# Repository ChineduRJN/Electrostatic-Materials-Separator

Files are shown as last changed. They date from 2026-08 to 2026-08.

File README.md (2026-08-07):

# Electrostatic Materials Separator — Embedded Control & High-Voltage System

A multidisciplinary industrial automation machine engineered to separate metallic and non-metallic particles using high-voltage electrostatic fields. This system integrates a master-slave dual-microcontroller architecture, custom mixed-signal conditioning circuits, high-power AC/DC switching, and a real-time graphical touchscreen interface.

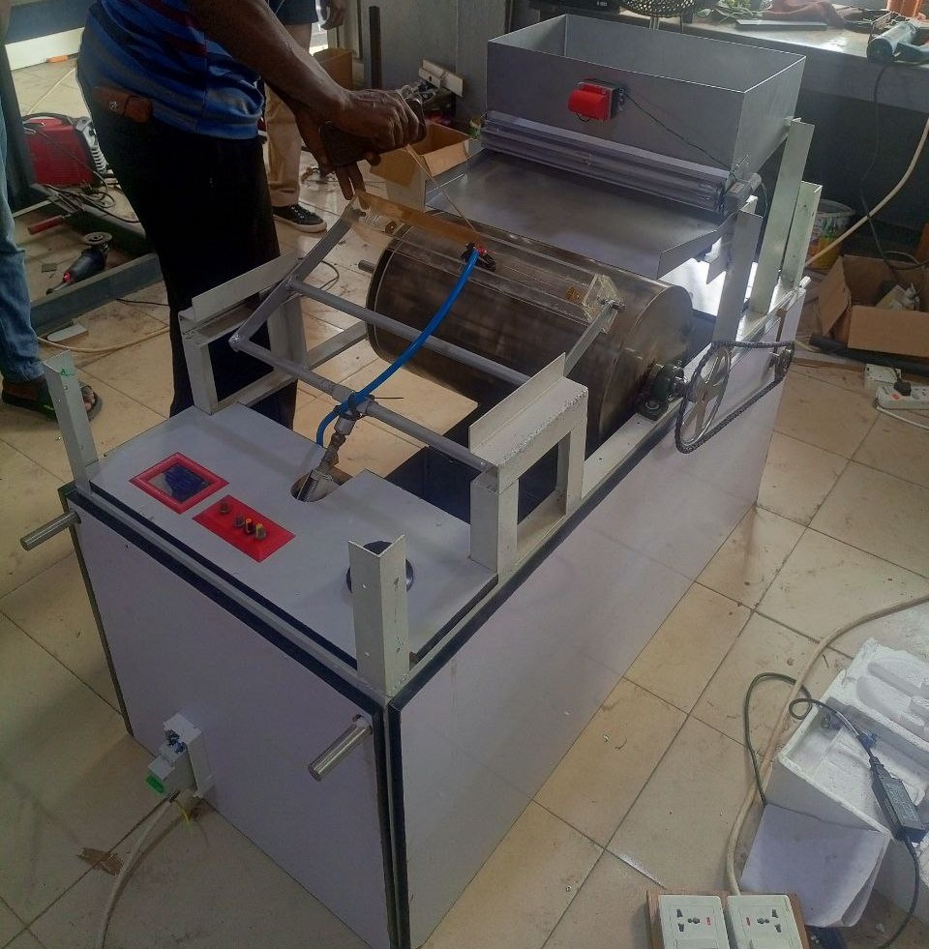
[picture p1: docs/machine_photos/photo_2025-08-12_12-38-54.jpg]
Electrostatic Separator Complete Assembly


---

## 📊 System Overview & Key Features

| Subsystem | Specification / Implementation | Technical Role |
| :--- | :--- | :--- |
| **Main System Controller** | **Arduino Mega 2560 Pro** | Central brain; executes UI rendering, Variac voltage sampling, and actuator PWM logic |
| **Dedicated Sensor Node** | **Arduino Pro Mini** | Dedicated edge processor; samples Hall sensor pulses and computes drum RPM |
| **Inter-MCU Communication** | **SPI / UART Handshake** | Real-time sensor telemetry transfer from slave (Pro Mini) to master (Mega) |
| **High-Voltage Generation** | **Variac & Step-Up Transformer** | Generates adjustable electrostatic field for metallic particle deflection |
| **HV Signal Conditioning** | **Op-Amps, TIP31C, Passive Filters** | Steps down and buffers transformer feedback for accurate microcontroller ADC monitoring |
| **Interactive UI** | **3.5" ILI9488 TFT Touchscreen** | Graphical display rendering live RPM, electrostatic voltage (kV), feeder rate, and vibration % |
| **Actuation & Feeding** | **ESC, DC Motor, 2x Tray Vibrators** | Regulates drum rotation speed and consistent feeder tray/hopper material flow (0–100%) |

---

## 🛠️ Key Engineering Highlights

### 1. Master-Slave Dual-Microcontroller Architecture
* **Task Offloading:** To prevent display rendering loops on the **Arduino Mega 2560 Pro** from missing high-speed sensor interrupts, an **Arduino Pro Mini** was deployed as a dedicated sensor coprocessor  .
* **RPM Acquisition:** The Pro Mini continuously captures pulses from a magnetic **Hall effect sensor** mounted on the rotating separation drum, calculates instantaneous revolutions per minute (RPM), and transmits structured telemetry packets to the main controller over **SPI**  .

### 2. High-Voltage Signal Conditioning & Mixed-Signal PCB
* **Transformer Feedback Monitoring:** Designed and soldered an analog signal conditioning circuit using **operational amplifiers, capacitors, diodes, resistors, and TIP31C power transistors**  .
* **Safe ADC Sampling:** This circuit conditions and scales the high-voltage output from the Variac/transformer stage into a safe, linear 0–5V analog range, allowing the Mega to monitor and display live electrostatic voltage (in kV) on the touchscreen.
* **Power & Noise Isolation:** Implemented an **XL4015 DC-DC buck converter** to supply a clean 5V rail to the logic boards, isolating the low-voltage microcontrollers from electromagnetic noise generated by the industrial AC contactors and feeder vibrators  .

### 3. Real-Time Graphical UI & Electromechanical Control
* **TFT Interface:** Programmed a graphical dashboard on an **ILI9488 TFT screen** to give operators real-time feedback on drum speed, feeder speed, electrostatic voltage, and vibration intensity  .
* **Precision Material Flow:** Configured PWM control logic to independently drive an **Electronic Speed Controller (ESC)** for drum rotation and dual industrial vibrators on the feeder tray and hopper (adjustable from 0% to 100% intensity)  .

---

## 📂 Repository Structure

```text
Electrostatic-Materials-Separator/
├── firmware/
│   ├── mega_main_controller/    # Arduino Mega 2560 Pro code (TFT UI, Actuators & Main Loop)
│   └── pro_mini_rpm_sensor/     # Arduino Pro Mini code (Hall Sensor Interrupts & SPI Transmit)
├── hardware/
│   ├── schematics/              # Signal conditioning schematic diagrams & PCB layouts
│   └── bom.md                   # Complete Bill of Materials (Electronics, HV & Mechanical)
└── docs/
    ├── machine_photos/          # Finished machine, wooden/glass casing, and TFT display
    └── assembly_and_wiring/     # Internal control wiring, terminal blocks, and mechanical frame

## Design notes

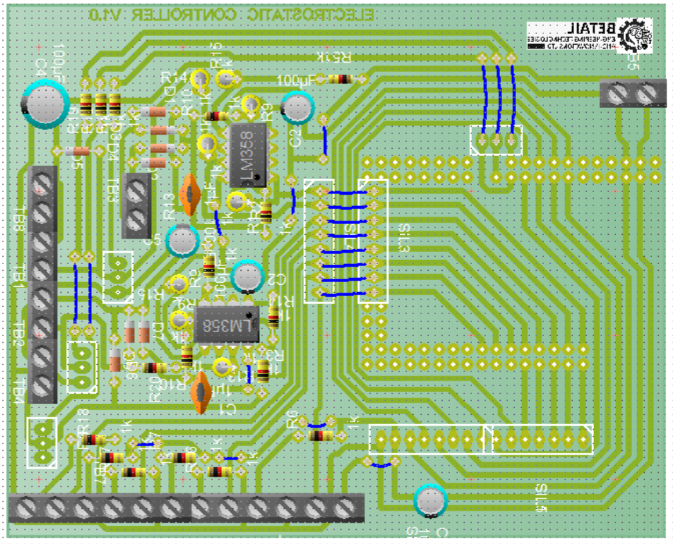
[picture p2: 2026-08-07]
hardware/schematics/pcb1.png

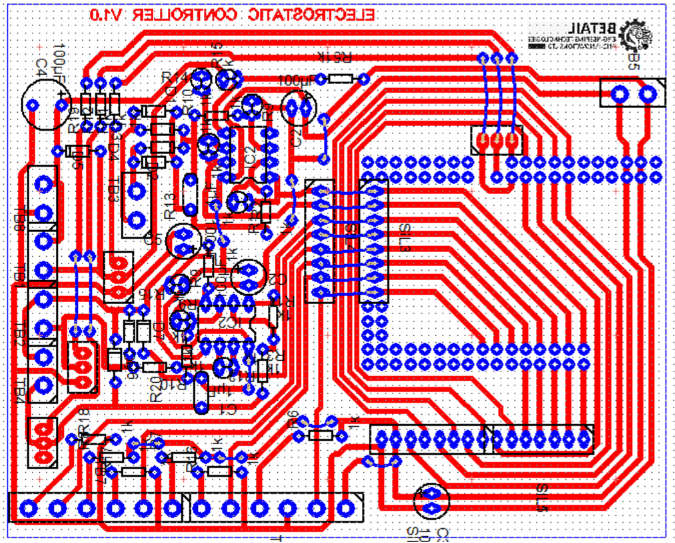
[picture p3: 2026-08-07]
hardware/schematics/pcb2.png

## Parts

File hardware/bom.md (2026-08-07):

# Bill of Materials (BoM) — Electrostatic Materials Separator

| Subsystem | Component | Purpose / Description |
| :--- | :--- | :--- |
| **Microcontrollers** | Arduino Mega 2560 Pro | Central controller; manages TFT display, Variac voltage sampling, and actuator logic |
| **Microcontrollers** | Arduino Pro Mini | Dedicated sensor node; processes Hall sensor pulses for RPM and sends over SPI/UART |
| **User Interface** | ILI9488 TFT Screen | Graphical display showing live RPM, voltage (kV), feeder speed, and vibration % |
| **High Voltage** | Variac & Transformer | Generates adjustable electrostatic field for metallic/non-metallic separation |
| **Power Supply** | XL4015 DC-DC Buck | Steps down input supply to provide a stable 5V rail for microcontrollers |
| **Power Switching** | Industrial Contactors | High-power AC switching for main system power and motor isolation |
| **Signal Conditioning** | TIP31C & Op-Amps | Amplifies and conditions high-voltage transformer feedback for ADC monitoring |
| **Electromechanical** | Hall Effect Sensor | Measures drum revolutions per minute via mounted neodymium magnets |
| **Electromechanical** | ESC & Drum Motor | Regulates rotating drum speed using microcontroller PWM control |
| **Electromechanical** | 2x Tray Vibrators | Controls steady material flow across the feeder tray and hopper (0–100% intensity) |

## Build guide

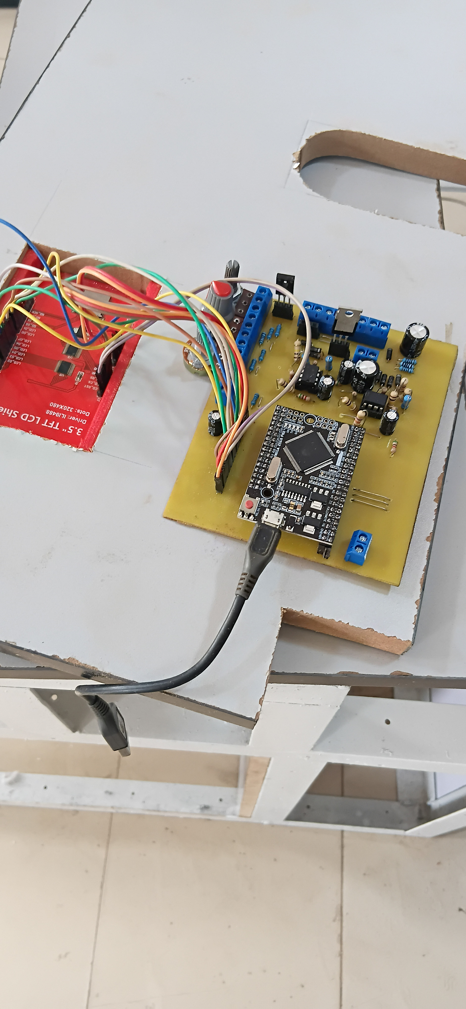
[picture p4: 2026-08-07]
docs/assembly_and_wiring/20250806_120954.jpg

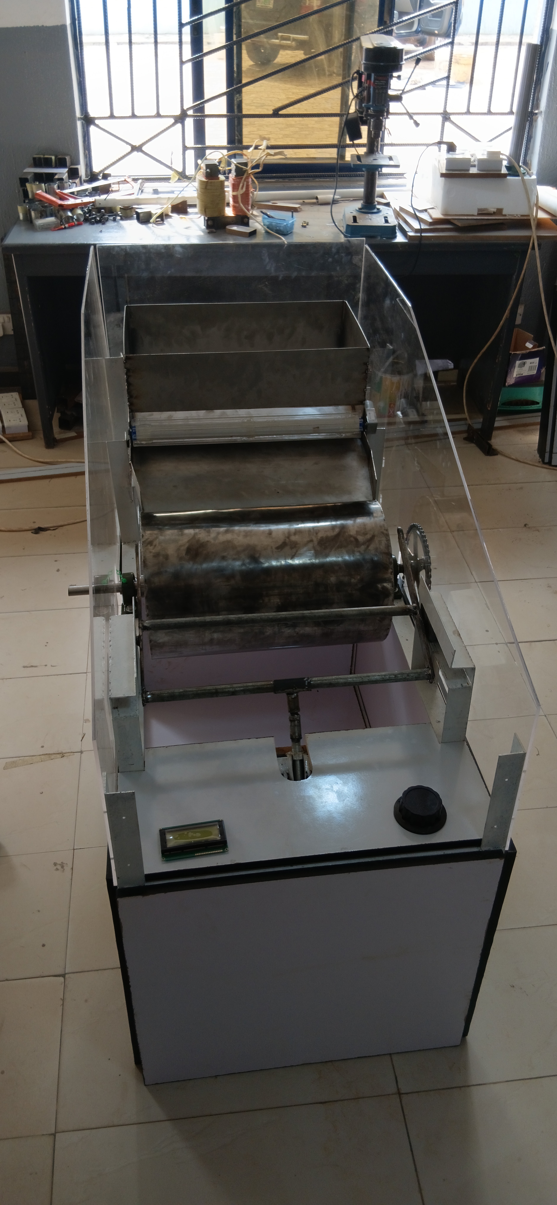
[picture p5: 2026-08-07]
docs/assembly_and_wiring/20250730_100324.jpg

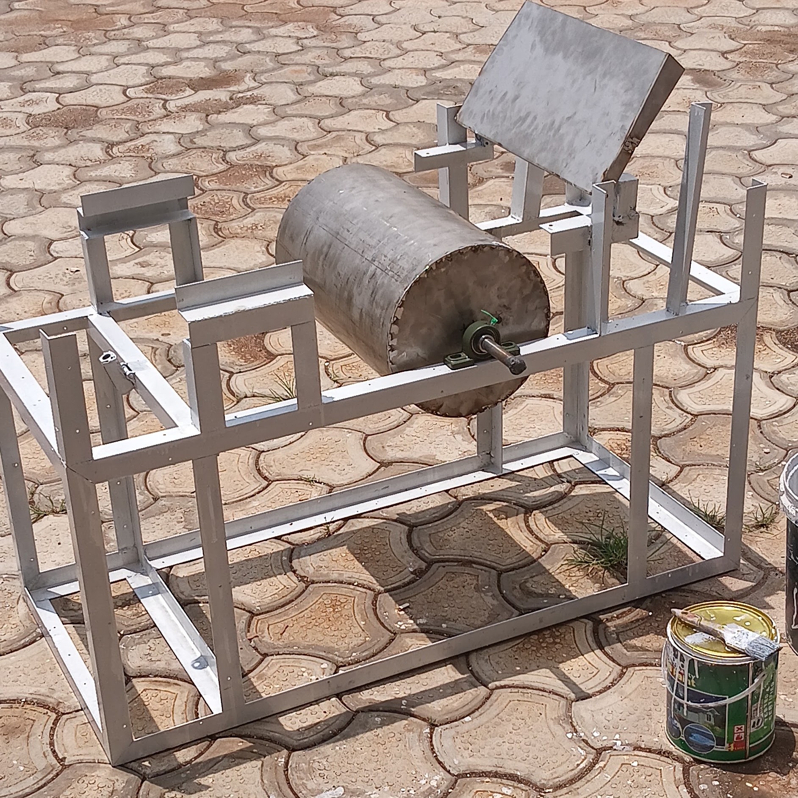
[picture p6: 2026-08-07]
docs/assembly_and_wiring/20250729_120056.jpg

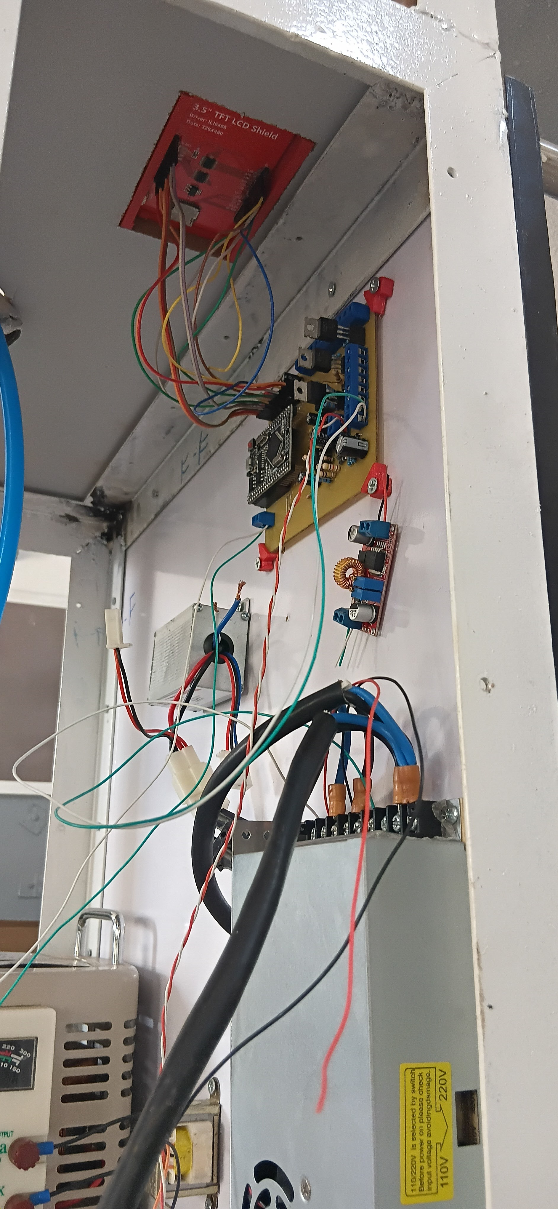
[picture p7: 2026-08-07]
docs/assembly_and_wiring/20250809_114631 (2).jpg

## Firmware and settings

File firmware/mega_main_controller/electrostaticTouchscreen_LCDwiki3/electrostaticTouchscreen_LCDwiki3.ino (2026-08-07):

#include <LCDWIKI_GUI.h> // Core graphics library
#include <LCDWIKI_KBV.h> // Hardware-specific library
#include <TouchScreen.h> // Touchscreen support

// Initialize TFT screen
LCDWIKI_KBV tft(320, 480, A6, A4, A2, A0, A8);//width,height,cs,cd,wr,rd,reset

// Colors
#define BLACK        0x0000
#define BLUE         0x001F
#define RED          0xF800
#define GREEN        0x07E0
#define CYAN         0x07FF
#define MAGENTA      0xF81F
#define YELLOW       0xFFE0
#define WHITE        0xFFFF
#define NAVY         0x000F
#define DARKGREEN    0x03E0
#define DARKCYAN     0x03EF
#define MAROON       0x7800
#define PURPLE       0x780F 
#define OLIVE        0x7BE0 
#define GREY         0xC618 
#define DARKGREY     0x7BEF
#define ORANGE       0xFD20
#define GREENYELLOW  0xAFE5
#define PINK         0xF81F

// Touchscreen pins
#define YP A2
#define XM A3
#define YM 8
#define XP 9
TouchScreen ts = TouchScreen(XP, YP, XM, YM, 300);

// Calibrated values from touch test
#define TS_LEFT  93
#define TS_RT    926
#define TS_TOP   879
#define TS_BOT   154

// Pin definitions
#define energies_pin 17
#define feed_pin 10
#define hopper_pin 12
#define tray_pin 11
#define drumCont 46

// Serial communication for RPM data
#define rpmSerial Serial1

TSPoint p;
    
//Controls
int feed_nobe = A13;
int hopper_nobe = A11;
int tray_nobe = A9;

int feed_nobe_val;
int hopper_nobe_val;
int tray_nobe_val;

int * feed_val = &feed_nobe_val;
int * hopper_val = &hopper_nobe_val;
int * tray_val = &tray_nobe_val;

//Sensors
int staticVolt_meter = A1;
int feed_meter = A3;
int hopper_meter = A5;
int tray_meter = A7;
int drum_meter;

bool isRunning = false;
unsigned long lastUpdateTime = 0;
unsigned long * lastUpdateTime_P = &lastUpdateTime;
unsigned long TouchInt = 0;
unsigned long * TouchInt_P = &TouchInt;
const unsigned long updateInterval = 2000;
const unsigned long * updateInterval_P = &updateInterval;

unsigned long distime = 0;
unsigned long * dis_t = &distime;

// RPM variables 
int rawDrumSpeed = 0;        // Raw RPM value from Arduino Pro Mini
int drumSpeed = 0;           // Calibrated RPM value for display
unsigned long lastRpmReceived = 0;  // Timestamp of last RPM data received

int * drumSpeed_P = &drumSpeed;
double electrostatic = 0.00;
double * electrostatic_P = &electrostatic;
int feedSpeed = 1;
int * feedSpeed_P = &feedSpeed;
int hopperVib = 1;
int * hopperVib_P = &hopperVib;
int trayVib = 1;
int * trayVib_P = &trayVib;

// Cache previous values to reduce flickering
int lastDrumSpeed;
int * lastDrumSpeed_P = &lastDrumSpeed;
float lastElectrostatic;
float * lastElectrostatic_P = &lastElectrostatic;
float lastFeedSpeed;
float * lastFeedSpeed_P = &lastFeedSpeed;
float lastHopperVib;
float * lastHopperVib_P = &lastHopperVib;
float lastTrayVib;
float * lastTrayVib_P = &lastTrayVib;

// Positions
int yStart = 100;
int * yStart_P = &yStart;
int spacing = 40;
int * spacing_P = &spacing;
int valueX = 200;
int * valueX_P = &valueX;
int unitX = 290;
int * unitX_P = &unitX;

//  RPM Data Reading Function
void readRPMData() {
  // Check for incoming RPM data from Arduino Pro Mini
  if (rpmSerial.available()) {
    String rpmString = rpmSerial.readStringUntil('\n');
    rawDrumSpeed = rpmString.toInt();
    
    // Apply calibration factor only once when receiving new data
    drumSpeed = rawDrumSpeed * 0.3289;  // Your calibration factor
    
    lastRpmReceived = millis();
  }
  
  // Timeout handling - set RPM to 0 if no data received for 1 second
  if (millis() - lastRpmReceived > 1000) {
    drumSpeed = 0;
    rawDrumSpeed = 0;
  }
}

void showIntroScreen() {
  tft.Fill_Screen(BLACK);
  tft.Set_Text_Back_colour(BLACK);
  tft.Set_Text_colour(CYAN);
  tft.Set_Text_Size(6);
  tft.Print_String("BETAIL.NG", CENTER, 130);

  delay(3000); // show for 3 seconds
}

void drawStaticLabels() {
  tft.Set_Text_colour(WHITE);
  tft.Set_Text_Back_colour(BLACK);
  tft.Set_Text_Size(2);

  // Labels
  tft.Print_String("Drum speed:", 10, *yStart_P);
  tft.Print_String("Electrostatic:", 10, *yStart_P + *spacing_P);
  tft.Print_String("Feeding speed:", 10, *yStart_P + 2 * *spacing_P);
  tft.Print_String("Hopper vibrator:", 10, *yStart_P + 3 * *spacing_P);
  tft.Print_String("Tray vibrator:", 10, *yStart_P + 4 * *spacing_P);

  // Units (static)
  tft.Print_String("RPM", *unitX_P, *yStart_P);
  tft.Print_String("kV", *unitX_P, *yStart_P + *spacing_P);
  tft.Print_String("RPM", *unitX_P, *yStart_P + 2 * *spacing_P);
  tft.Print_String("%", *unitX_P, *yStart_P + 3 * *spacing_P);
  tft.Print_String("%", *unitX_P, *yStart_P + 4 * *spacing_P);
}

void updateValues() {
  tft.Set_Text_Mode(1);
  tft.Set_Text_colour(WHITE);
  tft.Set_Text_Back_colour(BLACK);
  tft.Set_Text_Size(2);

  char buf[6];
  int boxWidth = 80; // width of the value display box (pixels)
  int charWidth = 6 * tft.Get_Text_Size(); // width of one char
  int x;

  if (*drumSpeed_P != *lastDrumSpeed_P) {
    sprintf(buf, "%3d", *drumSpeed_P); // Display as integer RPM
    int textWidth = strlen(buf) * charWidth;
    x = valueX + boxWidth - textWidth;
    tft.Fill_Rect(*valueX_P, *yStart_P, boxWidth, *spacing_P, BLACK);
    tft.Print_String(buf, x, *yStart_P);
    *lastDrumSpeed_P = *drumSpeed_P;
  }
  
  if (*electrostatic_P != *lastElectrostatic_P) {
    dtostrf(*electrostatic_P, 5, 2, buf);
    int textWidth = strlen(buf) * charWidth;
    x = valueX + boxWidth - textWidth;
    tft.Set_Text_colour(isRunning ? RED : WHITE);
    tft.Fill_Rect(*valueX_P, *yStart_P + *spacing_P, boxWidth, *spacing_P, BLACK);
    tft.Print_String(buf, x, *yStart_P + *spacing_P);
    *lastElectrostatic_P = *electrostatic_P;
    tft.Set_Text_colour(WHITE);
  }
  
  if (*feedSpeed_P != *lastFeedSpeed_P) {
    dtostrf(*feedSpeed_P, 5, 2, buf);
    int textWidth = strlen(buf) * charWidth;
    x = valueX + boxWidth - textWidth;
    tft.Fill_Rect(*valueX_P, *yStart_P + 2 * *spacing_P, boxWidth, *spacing_P, BLACK);
    tft.Print_String(buf, x, *yStart_P + 2 * *spacing_P);
    *lastFeedSpeed_P = *feedSpeed_P;
  }

  if (*hopperVib_P != *lastHopperVib_P) {
    sprintf(buf, "%3d", *hopperVib_P); // fixed-width 3-digit integer
    int textWidth = strlen(buf) * charWidth;
    x = valueX + boxWidth - textWidth;
    tft.Fill_Rect(*valueX_P, *yStart_P + 3 * *spacing_P, boxWidth, *spacing_P, BLACK);
    tft.Print_String(buf, x, *yStart_P + 3 * *spacing_P);
    *lastHopperVib_P = *hopperVib_P;
  }

  if (*trayVib_P != *lastTrayVib_P) {
    sprintf(buf, "%3d", *trayVib_P);
    int textWidth = strlen(buf) * charWidth;
    x = valueX + boxWidth - textWidth;
    tft.Fill_Rect(*valueX_P, *yStart_P + 4 * *spacing_P, boxWidth, *spacing_P, BLACK);
    tft.Print_String(buf, x, *yStart_P + 4 * *spacing_P);
    *lastTrayVib_P = *trayVib_P;
  }
}

void show_string(uint8_t *str,int16_t x,int16_t y,double csize,uint16_t fc, uint16_t bc,boolean mode)
{
    tft.Set_Text_Mode(mode);
    tft.Set_Text_Size(csize);
    tft.Set_Text_colour(fc);
    tft.Set_Text_Back_colour(bc);
    tft.Print_String(str,x,y);
}

void getVal(double * a_val, int aveg, int log_pin){
  double sum = 0.0;
  for (int i=0; i<aveg; i++){
    sum = sum + analogRead(log_pin);
    delay(5);
  }
  *a_val = sum/aveg;
}

void getValint(int * a_val, int aveg, int log_pin){
  int sum = 0.0;
  for (int i=0; i<aveg; i++){
    sum = sum + analogRead(log_pin);
    delay(5);
  }
  *a_val = sum/aveg;
}

void randomizeValues() {
  getVal(&electrostatic, 15, staticVolt_meter);

  //  Removed the problematic line that was continuously modifying drumSpeed
  // *drumSpeed_P = *drumSpeed_P * 0.3289;  // REMOVED THIS LINE
  
  *electrostatic_P = (*electrostatic_P/1023 * 5.00) * 75.00;

// Hopper Vibration Control
  *hopperVib_P = map(*hopperVib_P, 0, 128, 0, 178);
  *hopper_val = map(*hopper_val, 100, 975, 0, 178);
  
  int pinWriter = *hopperVib_P;
  if (*hopper_val > pinWriter) {
    while (*hopper_val > pinWriter) pinWriter++;
  }
  else if (*hopper_val < pinWriter) {
    while (*hopper_val < pinWriter) pinWriter--;
  }
  pinWriter = constrain(pinWriter,0,178);
  analogWrite(hopper_pin, pinWriter);
  *hopperVib_P = map(pinWriter,0,178,0,100);
  
// Tray Vibration Control
  *trayVib_P = map(*trayVib_P, 0, 128, 0, 178);
  *tray_val = map(*tray_val, 100, 975, 0, 178);
  
  pinWriter = *trayVib_P;
  if (*tray_val > pinWriter) {
    while (*tray_val > pinWriter) pinWriter++;
  }
  else if (*tray_val < pinWriter) {
    while (*tray_val < pinWriter) pinWriter--;
  }
  pinWriter = constrain(pinWriter,0,178);
  analogWrite(tray_pin, pinWriter);
  *trayVib_P = map(pinWriter,0,178,0,100);

// Feed Speed Control
  *feedSpeed_P = map(*feedSpeed_P, 120, 150, 0, 255);
  *feed_val = map(*feed_val, 0, 1000, 0, 255);
  
  pinWriter = *feedSpeed_P;
  if (*feed_val > pinWriter) {
    while (*feed_val > pinWriter) pinWriter++;
  }
  else if (*feed_val < pinWriter) {
    while (*feed_val < pinWriter) pinWriter--;
  }
  pinWriter = constrain(pinWriter,0,255);
  analogWrite(feed_pin, pinWriter);
  *feedSpeed_P = map(pinWriter,0,255,0,18);
}

void metering(){
  ReadWrite(&feedSpeed, feed_meter, &feed_nobe_val, feed_nobe, feed_pin);
  ReadWrite(&hopperVib, hopper_meter, &hopper_nobe_val, hopper_nobe, hopper_pin);
  ReadWrite(&trayVib, tray_meter, &tray_nobe_val, tray_nobe, tray_pin);
}

int ReadWrite(int * meterVal, int meterPin, int * nodeVal, int NobePin, int pin){
  int sum = 0;  // Initialize sum
  
  for (int i=0; i<5; i++){
    sum = sum + analogRead(NobePin);
    delay(20);
  }
  *nodeVal = sum/5;
  
  sum = 0;  // Reset sum
  for (int i=0; i<10; i++){
    sum = sum + analogRead(meterPin);
    delay(20);
  }
  *meterVal = sum/10;
  
  return 0; // Added return value
}

void setup() {
  // Initialize serial communication for RPM data
  rpmSerial.begin(9600);
  
  // Initialize pins
  pinMode(energies_pin, OUTPUT);
  pinMode(feed_pin, OUTPUT);
  pinMode(hopper_pin, OUTPUT);
  pinMode(tray_pin, OUTPUT);
  
  // Initialize display
  tft.Init_LCD();
  tft.Set_Rotation(1);

  showIntroScreen();

  tft.Fill_Screen(BLACK);

  tft.Set_Text_colour(CYAN);
  tft.Set_Text_Back_colour(BLACK);
  tft.Set_Text_Size(3);
  tft.Print_String("Electrostatic", CENTER, 10);
  tft.Print_String("Separator", CENTER, 45);

  tft.Draw_Line(0, 80, 480, 80);
  tft.Draw_Line(335, 80, 335, 320);

  drawStaticLabels();
  updateValues();
  distime = millis();
  
  // Initialize RPM timing
  lastRpmReceived = millis();
}

void loop() {
  //Read RPM data from Arduino Pro Mini
  readRPMData();

  // Read control inputs and update outputs
  metering();
  
  // Drum speed control from potentiometer
  int sum = 0;
  for(int i=0; i<10; i++){
    sum += analogRead(A15);
    delay(10);
  }
  sum /= 10;
  sum = map(sum, 0, 1023, 0, 130);
  analogWrite(drumCont, sum);

  // Update display every 150ms
  if ((millis()-*dis_t) > 150){
      randomizeValues();
      updateValues();
      *dis_t = millis();
      
      // Optional: Debug output to monitor RPM communication
      // Serial.print("Raw RPM: "); Serial.print(rawDrumSpeed);
      // Serial.print(" Calibrated: "); Serial.println(drumSpeed);
  }
}

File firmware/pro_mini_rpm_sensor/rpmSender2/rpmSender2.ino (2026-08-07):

// ======== RPM SENSOR - ARDUINO PRO MINI ========
// This code measures drum RPM using a hall sensor and sends it to Mega2560

// Use Hardware Serial for communication with Mega2560
// Connect: Pro Mini TX (pin 1) -> Mega2560 RX1 (pin 19)
// Connect: Pro Mini RX (pin 0) -> Mega2560 TX1 (pin 18)
// Connect: GND -> GND

// ======== SETTINGS ========
const byte hallPin = 2;           // Interrupt pin (must be 2 or 3 on Pro Mini)
const byte pulsesPerRev = 1;      // Number of magnets/pulses per revolution

// ======== VARIABLES ========
volatile unsigned long lastPulseTime = 0;
volatile unsigned long pulseInterval = 0;
volatile bool newPulse = false;

unsigned long rpm = 0; 
unsigned long lastSendTime = 0;  
unsigned long lastRpmCalculation = 0;
const unsigned long sendInterval = 100;    // Send every 100ms for smooth display
const unsigned long rpmTimeout = 2000000;  // 2 seconds timeout (2,000,000 microseconds)

// ======== INTERRUPT ROUTINE ========
void pulseISR() {
  unsigned long now = micros();
  
  // Debounce: ignore pulses less than 5ms apart
  if (now - lastPulseTime > 5000) {
    pulseInterval = now - lastPulseTime;
    lastPulseTime = now;
    newPulse = true;
  }
}

void setup() {
  Serial.begin(9600);  // Use hardware serial for communication
  pinMode(hallPin, INPUT_PULLUP);  // Enable internal pullup
  attachInterrupt(digitalPinToInterrupt(hallPin), pulseISR, FALLING);  // Trigger on falling edge
  
  // Send initial zero value
  Serial.println("0");
}

void loop() {
  unsigned long currentTime = micros();
  
  // Calculate RPM when we have a new pulse
  if (newPulse) {
    noInterrupts();
    unsigned long interval = pulseInterval;
    newPulse = false;
    interrupts();
    
    if (interval > 0) {
      // RPM = (60 seconds * 1,000,000 microseconds) / (interval * pulses per rev)
      rpm = (60UL * 1000000UL) / (interval * pulsesPerRev);
      lastRpmCalculation = currentTime;
    }
  }
  
  // Check for timeout (drum stopped)
  if (currentTime - lastPulseTime > rpmTimeout) {
    rpm = 0;
  }
  
  // Send RPM data at regular intervals
  if (millis() - lastSendTime >= sendInterval) {
    Serial.println(rpm);
    lastSendTime = millis();
  }
  
  delay(10); // Small delay to prevent overwhelming the loop
}

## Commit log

2026-08-07 Add files via upload
    Initial commit: Add dual-MCU firmware, high-voltage conditioning schematics, and machine photos
    [Electrostatic GUI and Metering.drl]
2026-08-07 Add Bill of Materials for Electrostatic Separator
